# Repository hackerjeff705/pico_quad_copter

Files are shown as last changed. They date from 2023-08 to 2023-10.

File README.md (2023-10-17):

# pico_quad_copter Flight controller code overview
The flight controller code is responsible for reading the data from the various sensors, calculating the PID outputs, and setting the speed of the motors.

## Sensor input

The first section of the code reads the data from the various sensors on the flight controller. This includes the gyro data, the accelerometer data, and the receiver input data.

The gyro data is used to measure the angular rate of the drone. The accelerometer data is used to measure the acceleration of the drone. The receiver input data is used to control the drone.

## PID controller

The next section of the code calculates the PID outputs for the roll, pitch, and yaw axes. The PID controller is a control loop feedback mechanism that is used to maintain a desired setpoint. In this case, the desired setpoint is the angle of the drone.

The PID controller calculates the PID outputs using the following equation:

```PID output = Kp * error + Ki * integral + Kd * derivative```

where:
* ```Kp``` is the proportional gain
* ```Ki``` is the integral gain
* ```Kd``` is the derivative gain
* ```error``` is the difference between the desired setpoint and the current value
* ```integral``` is the sum of the past errors
* ```derivative``` is the rate of change of the error signal

The PID outputs are then limited to a maximum value to prevent overdriving the motors.

The calculate_pid() function that you provided is used to calculate the PID outputs for the roll, pitch, and yaw axes of a drone. The PID outputs are then used to control the speed of the motors.

The function works as follows:
* For each axis (roll, pitch, and yaw):
  * Calculate the PID error by subtracting the desired angular rate (PID setpoint) from the actual angular rate (gyro input).
  * Calculate the integral term by adding the product of the PID error and the integral gain to the integral memory variable.
  * Calculate the derivative term by subtracting the previous PID error from the current PID error and multiplying by the derivative gain.
  * Calculate the PID output by summing the proportional, integral, and derivative terms.
  * Limit the PID output to the maximum value for that axis.

## Motor control

The last section of the code sets the speed of the motors based on the PID outputs. The speed of the motors is controlled by sending a PWM signal to the electronic speed controllers (ESCs).

The ESCs then convert the PWM signal to a DC voltage, which controls the speed of the motors.

## Working systems

The flight controller code can be divided into the following working systems:
* Sensor input system: This system reads the data from the various sensors on the flight controller.
* PID controller system: This system calculates the PID outputs for the roll, pitch, and yaw axes.
* Motor control system: This system sets the speed of the motors based on the PID outputs.

These three systems work together to control the flight of the drone. The sensor input system provides the data needed by the PID controller system to calculate the PID outputs. The PID controller system calculates the PID outputs needed to maintain the desired angle of the drone. The motor control system then sets the speed of the motors based on the PID outputs, which causes the drone to move in the desired direction.

## Additional notes

* The flight controller code is a complex system, but it can be broken down into these three basic working systems. By understanding how these systems work together, you can better understand how the flight controller controls the flight of the drone.
* The PID gains are important parameters that affect the performance of the flight controller. The PID gains need to be tuned to achieve optimal performance.
* The flight controller code is typically written in C or C++.

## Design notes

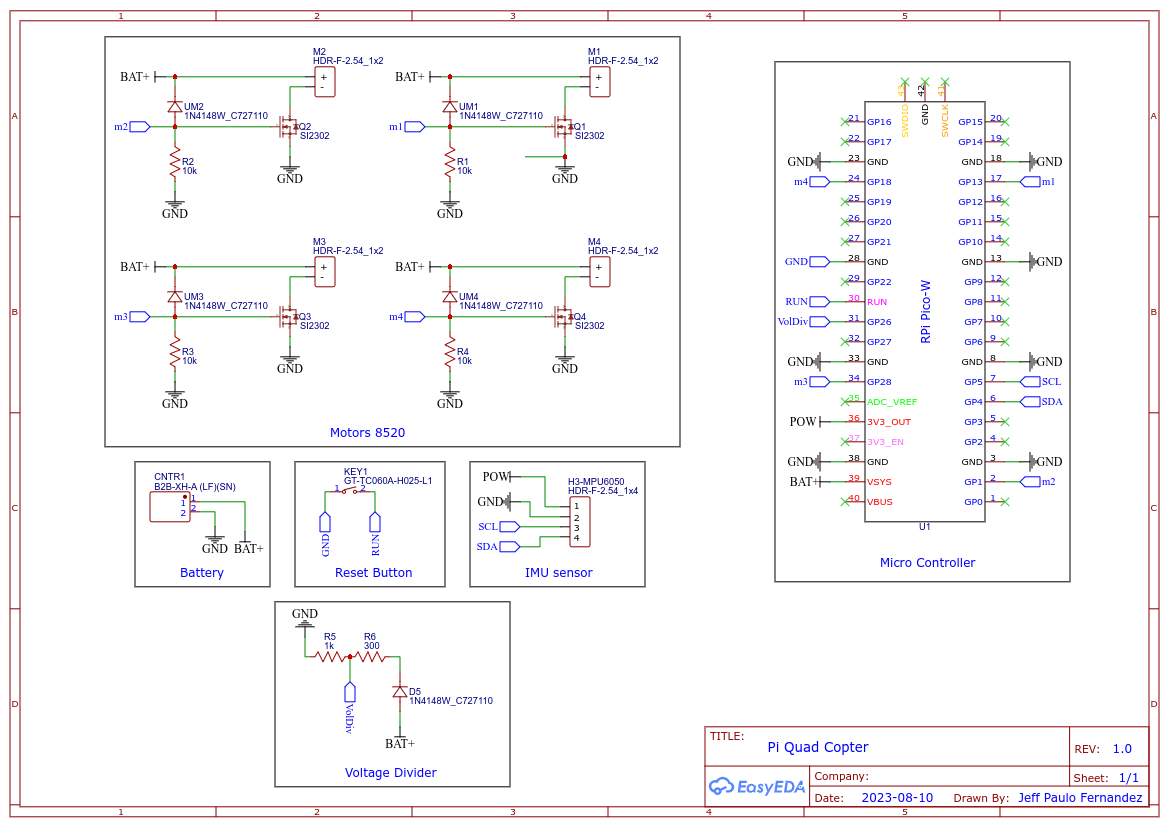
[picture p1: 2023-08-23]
hardware/schematic/Schematic_pi_quad_2023-08-23.png

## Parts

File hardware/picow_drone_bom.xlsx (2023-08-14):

 |  |  | TOTAL ESTIMATE | $59.3396
FINAL ASSEMBLY
Part name | MPN | qty | unit price | total price | link | notes | needed for PCB design?
8520 Drone frame |  | 1 | $12.6900 | $12.6900 | https://www.amazon.com/usmile-Lightweight-Brushed-Quadcopter-Support/dp/B01MU440T0 | Usmile® Super Lightweight 100mm Micro Brushed Carbon Fiber Quadcopter Frame for Mini Micro FPV Racing Support for 820 8.5 * 20mm Motor | N
Raspberry Pi Pico W | 5544 | 1 | $7.0000 | $7.0000 | https://www.adafruit.com/product/5544 | Raspberry Pi Pico WH - Pico Wireless with Headers Soldered | N
MPU6050 |  | 1 | $3.3300 | $3.3300 | https://www.amazon.com/HiLetgo-MPU-6050-Accelerometer-Gyroscope-Converter/dp/B00LP25V1A | HiLetgo 3pcs GY-521 MPU-6050 MPU6050 3 Axis Accelerometer Gyroscope Module 6 DOF 6-axis Accelerometer Gyroscope Sensor Module 16 Bit AD Converter Data Output IIC I2C for Arduino - Comes in packs of 3 | N
1S 360mAh Lipo Battery |  | 1 | $4.3300 | $4.3300 | https://www.amazon.com/GAONENG-300mAh-Battery-Powerwhoop-Connector/dp/B07L9RQNC3 | Gaoneng 6pcs 380mAh HV 1S Lipo Battery FPV Battery 60C/120C 3.8V with PH 2.0 Powerwhoop Connector for UZ65 US65 Tiny Whoop Drone Blade Inductrix - comes in packs of | N
8520 Coreless Motor (OPTION 1) |  | 4 | $2.3700 | $9.4800 | https://www.amazon.com/8-5x20mm-15000KV-Coreless-JST-1-25-Connector/dp/B07CFQMF1M | 8pcs 8520 Motor 8.5x20mm 15000KV Brushed Motors 4CW 4CCW Coreless Motor with JST-1.25 Connector for D JI Ryze Tello 720P Camera WiFi FPV RC Quadcopter M80S E013 Plus Tiny 8X Frame Kit etc - comes in packs of 8 - takes 3.2V | N
8520 Coreless Motor (OPTION 2) |  | 4 | $3.7500 | $15.0000 | https://www.amazon.com/USAQ-Coreless-Brushed-8-5x20mm-Propeller/dp/B06Y11C2HL | Set of 4 USAQ 8520 Coreless Brushed Motor 8.5x20mm 53,000rpm 65mm Propeller Set - (Operating Voltage: 3.7-4.2V, Operating Current: 0.08A-0.1A, Speed: 55,000RPM) | N
55mm Propeller (included with motors but I recommend buying extra) |  | 4 | $1.2000 | $4.8000 | https://www.amazon.com/USAQ-Pairs-KingKong-Propellers-Coreless/dp/B077WS9DY7 | USAQ 10 Pairs Kingkong 65mm Propellers for 716 720 8520 Coreless Motor Micro FPV Drone | N
BMP 280 (Not used yet but will be used in future) |  | 1 |  | $0.0000 |  |  | N
1S Lipo charger (OPTIONAL) |  | 1 |  | $0.0000 |  |  | N
FOR BUILDING PCB BOARD
Part name | MPN | qty | unit price | total price | link | notes | needed for PCB design?
si2302 N channel Mosfet | SI2302 | 4 | $0.0346 | $0.1384 | https://www.lcsc.com/product-detail/MOSFETs_BORN-SI2302_C344009.html |  | Y
1N4148WDiode | 1N4148W | 5 | $0.0066 | $0.0330 | https://www.lcsc.com/product-detail/Switching-Diode_TWGMC-1N4148W_C727110.html | 1N4148 | Y
300 ohm resistor | 0603WAF3000T5E | 1 | $0.0011 | $0.0011 | https://www.lcsc.com/product-detail/Chip-span-style-background-color-ff0-Resistor-span-Surface-Mount_UNI-ROYAL-Uniroyal-Elec-0603WAF3000T5E_C23025.html |  | Y
10k ohm resistor | 0603WAF1002T5E | 4 | $0.0009 | $0.0036 | https://www.lcsc.com/product-detail/Chip-span-style-background-color-ff0-Resistor-span-Surface-Mount_UNI-ROYAL-Uniroyal-Elec-0603WAF1002T5E_C25804.html |  | Y
1k ohm resistor | 0603WAF1001T5E | 1 | $0.0006 | $0.0006 | https://www.lcsc.com/product-detail/Chip-span-style-background-color-ff0-Resistor-span-Surface-Mount_UNI-ROYAL-Uniroyal-Elec-0603WAF1001T5E_C21190.html |  | Y
Male Pin headers | PZ254V-11-03P | 44 | $0.0162 | $0.7128 | https://www.lcsc.com/product-detail/Pin-span-style-background-color-ff0-Headers-span_XFCN-PZ254V-11-03P_C2937625.html | min qty 50 | Y
Female Pin headers | C2718488 | 40 | $0.0430 | $1.7200 | https://www.lcsc.com/product-detail/span-style-background-color-ff0-Female-span-Headers_BOOMELE-Boom-Precision-Elec-C2718488_C2718488.html | min qty 10 | Y
XH male connector | B2B-XH-A(LF)(SN) | 1 | $0.0328 | $0.0328 | https://www.lcsc.com/product-detail/Wire-To-Board-Wire-To-Wire-Connector_span-style-background-color-ff0-JST-span-Sales-America-B2B-XH-A-LF-SN_C158012.html |  | Y
Push Button | GT-TC060A-H025-L1 | 1 | $0.0673 | $0.0673 | https://www.lcsc.com/product-detail/Tactile-Switches_G-span-style-background-color-ff0-Switch-span-GT-TC060A-H025-L1_C5117870.html |  | Y

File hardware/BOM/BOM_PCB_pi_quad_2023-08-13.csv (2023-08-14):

Name | Designator | Footprint | Supplier Part
1N4148W_C727110 | D5,UM1,UM2,UM3,UM4 | SOD-123_L3.1-W1.7-LS3.7-RD | C727110
GT-TC060A-H025-L1 | KEY1 | SW-SMD_L6.1-W3.5-LS8.0 | C5117870
SI2302 | Q1,Q2,Q3,Q4 | SOT-23-3_L2.9-W1.3-P1.90-LS2.4-BR | C181087
10k | R1,R2,R3,R4 | R0603 | C25804
1k | R5 | R0603 | C21190
300 | R6 | R0603 | C23025
B2B-XH-A (LF)(SN) | CNTR1 | CONN-TH_B2B-XH-A-LF-SN | C158012
HDR-F-2.54_1x4 | H3-MPU6050 | HDR-F-2.54_1X4 | C225501
HDR-F-2.54_1x2 | M1,M2,M3,M4 | HDR-F-2.54_1X2 | C49661
C2718488 | U1 | RPI PICO-W | C2718488

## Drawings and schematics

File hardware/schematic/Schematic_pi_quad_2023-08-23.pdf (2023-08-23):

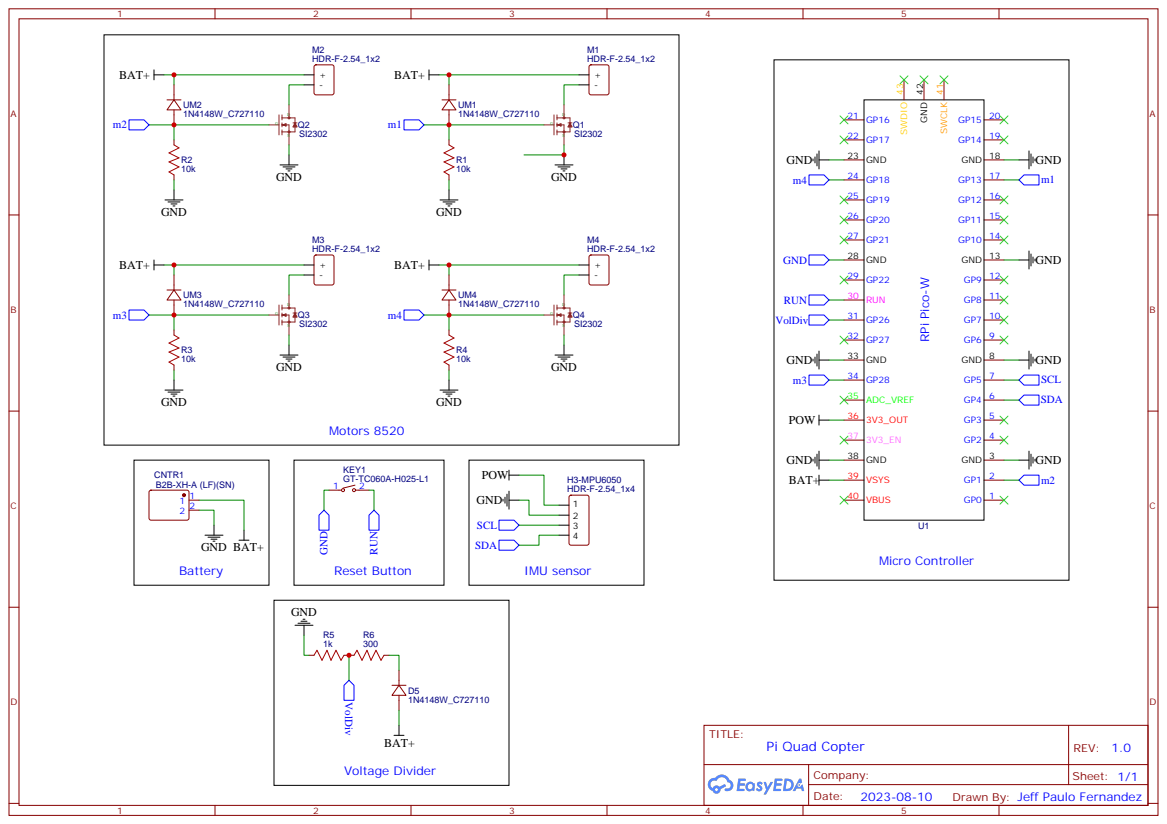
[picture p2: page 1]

Drawn By: Jeff Paulo Fernandez

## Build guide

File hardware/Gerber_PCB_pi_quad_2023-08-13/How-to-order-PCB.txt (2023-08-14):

How to Order PCB

Please refer to:
https://docs.easyeda.com/en/PCB/Order-PCB

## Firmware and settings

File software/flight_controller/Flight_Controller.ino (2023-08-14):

#include <Wire.h>                          //Include the Wire.h library so we can communicate with the gyro.
#include <WiFi.h>
#include <WiFiUdp.h>

#define I2C_CLK_FREQ 400000 // 400kHz
const u_int8_t IMUAddress = 0x68;  // Address for MPU6050 IMU sensor

#ifndef APSSID
#define APSSID "PicoW"
#define APPSW "password"
#endif
#define UDP_PKT_MAX_SIZE 16

unsigned int localPort = 8888;
char packetBuffer[UDP_PKT_MAX_SIZE + 1];

WiFiUDP Udp;  // Object for WiFi UDP class

#define MOT_TOP_LEFT 18
#define MOT_TOP_RIGHT 13
#define MOT_BOTTOM_LEFT 28
#define MOT_BOTTOM_RIGHT 1
#define sensitivity 2

///////////////////////////////////////////////////////////////////////////////////////////////////////////////////////////////////////
//PID gain and limit settings
///////////////////////////////////////////////////////////////////////////////////////////////////////////////////////////////////////
float pid_p_gain_roll = 1.3;               //Gain setting for the roll P-controller was 2.05
float pid_i_gain_roll = 0.013;              //Gain setting for the roll I-controller 0.04
float pid_d_gain_roll = 14.0;              //Gain setting for the roll D-controller was 11.0
int pid_max_roll = 300;                    //Maximum output of the PID-controller (+/-)

float pid_p_gain_pitch = pid_p_gain_roll;  //Gain setting for the pitch P-controller.
float pid_i_gain_pitch = pid_i_gain_roll;  //Gain setting for the pitch I-controller.
float pid_d_gain_pitch = pid_d_gain_roll;  //Gain setting for the pitch D-controller.
int pid_max_pitch = pid_max_roll;          //Maximum output of the PID-controller (+/-)

float pid_p_gain_yaw = 8.5;                //Gain setting for the pitch P-controller. //4.0
float pid_i_gain_yaw = 0.005;               //Gain setting for the pitch I-controller. //0.02
float pid_d_gain_yaw = 0.0;                //Gain setting for the pitch D-controller.
int pid_max_yaw = 300;                     //Maximum output of the PID-controller (+/-)

boolean auto_level = true;                 //Auto level on (true) or off (false)

///////////////////////////////////////////////////////////////////////////////////////////////////////////////////////////////////////
//Declaring global variables
///////////////////////////////////////////////////////////////////////////////////////////////////////////////////////////////////////
byte last_channel_1, last_channel_2, last_channel_3, last_channel_4;
byte highByte, lowByte;
volatile int receiver_input_channel_1 = 0, receiver_input_channel_2 = 0, receiver_input_channel_3 = 0, receiver_input_channel_4 = 0;
int counter_channel_1, counter_channel_2, counter_channel_3, counter_channel_4, loop_counter;
int esc_1, esc_2, esc_3, esc_4;
int throttle, battery_voltage;
int cal_int, start, gyro_address;
int receiver_input[5];
int temperature;
int16_t acc_axis[4], gyro_axis[4];
float roll_level_adjust, pitch_level_adjust;

long acc_x, acc_y, acc_z, acc_total_vector;
unsigned long timer_channel_1, timer_channel_2, timer_channel_3, timer_channel_4, esc_timer, esc_loop_timer;
unsigned long timer_1, timer_2, timer_3, timer_4, current_time;
unsigned long loop_timer;
double gyro_pitch, gyro_roll, gyro_yaw;
double gyro_axis_cal[4];
float pid_error_temp;
float pid_i_mem_roll, pid_roll_setpoint, gyro_roll_input, pid_output_roll, pid_last_roll_d_error;
float pid_i_mem_pitch, pid_pitch_setpoint, gyro_pitch_input, pid_output_pitch, pid_last_pitch_d_error;
float pid_i_mem_yaw, pid_yaw_setpoint, gyro_yaw_input, pid_output_yaw, pid_last_yaw_d_error;
float angle_roll_acc, angle_pitch_acc, angle_pitch, angle_roll;
boolean gyro_angles_set;

///////////////////////////////////////////////////////////////////////////////////////////////////////////////////////////////////////
//Setup routine
///////////////////////////////////////////////////////////////////////////////////////////////////////////////////////////////////////
void setup(){
  
  analogWriteFreq(500); // PWM frequency 500 Hz
  analogWriteRange(1000); // value coresponding to 100% PWM duty cycle

  Serial.begin(115200);
  gyro_address = IMUAddress;      
  Wire.setClock(I2C_CLK_FREQ);   
  Wire.begin();                                                             //Start the I2C as master.

  pinMode(MOT_TOP_LEFT, OUTPUT);
  pinMode(MOT_TOP_RIGHT, OUTPUT);
  pinMode(MOT_BOTTOM_LEFT, OUTPUT);
  pinMode(MOT_BOTTOM_RIGHT, OUTPUT);
  pinMode(LED_BUILTIN, OUTPUT);
  analogWrite(MOT_TOP_LEFT, 0);
  analogWrite(MOT_TOP_RIGHT, 0);
  analogWrite(MOT_BOTTOM_LEFT, 0);
  analogWrite(MOT_BOTTOM_RIGHT, 0);
  
  //Use the led on the Arduino for startup indication.
  digitalWrite(LED_BUILTIN,HIGH);                                                    //Turn on the warning led.

  set_gyro_registers();                                                     //Set the specific gyro registers.

  //Let's take multiple gyro data samples so we can determine the average gyro offset (calibration).
  for (cal_int = 0; cal_int < 2000 ; cal_int ++){                           //Take 2000 readings for calibration.
    if(cal_int % 15 == 0)
      digitalWrite(LED_BUILTIN, !digitalRead(LED_BUILTIN));                //Change the led status to indicate calibration.
    gyro_signalen();                                                        //Read the gyro output.
    gyro_axis_cal[1] += gyro_axis[1];   
    gyro_axis_cal[2] += gyro_axis[2];
    gyro_axis_cal[3] += gyro_axis[3];
    delay(4);                                                               //Wait 3 milliseconds before the next loop.
  }
  //Now that we have 2000 measures, we need to devide by 2000 to get the average gyro offset.
  gyro_axis_cal[1] /= 2000;                                                 //Divide the roll total by 2000.
  gyro_axis_cal[2] /= 2000;                                                 //Divide the pitch total by 2000.
  gyro_axis_cal[3] /= 2000;                                                 //Divide the yaw total by 2000.                                                //Set PCINT3 (digital input 11)to trigger an interrupt on state change.

  WiFi.mode(WIFI_AP);
  WiFi.begin(APSSID, APPSW);
  while(WiFi.status() != WL_CONNECTED) {
    Serial.print('.');    
    delay(500);    
  }
  Udp.begin(localPort);  
  //Wait until the receiver is active and the throtle is set to the lower position.
  while(receiver_input_channel_3 < 990 || receiver_input_channel_3 > 1020 || receiver_input_channel_4 < 1400){
    int packetSize = Udp.parsePacket();
    if(packetSize) {
      int n = Udp.read(packetBuffer, UDP_PKT_MAX_SIZE);
      packetBuffer[n] = '\0';
      char ch1[5], ch2[5], ch3[5], ch4[5];
      ch1[4] = '\0'; ch2[4] = '\0'; ch3[4] = '\0'; ch4[4] = '\0';
      for(int i=0; i<4; i++) {
        ch4[i] = packetBuffer[i];
        ch3[i] = packetBuffer[i+4];
        ch1[i] = packetBuffer[i+8];
        ch2[i] = packetBuffer[i+12];     
      }
      receiver_input_channel_1 = atoi(ch1); // ROLL
      receiver_input_channel_2 = atoi(ch2); // PITCH
      receiver_input_channel_3 = atoi(ch3); // THROTTLE
      receiver_input_channel_4 = atoi(ch4); // YAW
    }
    start ++;
    delay(3);                                                               //Wait 3 milliseconds before the next loop.
    if(start == 125){                                                       //Every 125 loops (500ms).
      digitalWrite(LED_BUILTIN, !digitalRead(LED_BUILTIN));                                   //Change the led status.
      start = 0;                                                            //Start again at 0.
    }
  }
  start = 0;                                                                //Set start back to 0.

  //Load the battery voltage to the battery_voltage variable.
  //65 is the voltage compensation for the diode.
  //12.6V equals ~5V @ Analog 0.
  //12.6V equals 1023 analogRead(0).
  //1260 / 1023 = 1.2317.
  //The variable battery_voltage holds 1050 if the battery voltage is 10.5V.
  //battery_voltage = (analogRead(0) + 65) * 1.2317;

  loop_timer = micros();                                                    //Set the timer for the next loop.

  //When everything is done, turn off the led.
  digitalWrite(LED_BUILTIN,LOW);                                                     //Turn off the warning led.
}
///////////////////////////////////////////////////////////////////////////////////////////////////////////////////////////////////////
//Main program loop
///////////////////////////////////////////////////////////////////////////////////////////////////////////////////////////////////////
void loop(){
  int packetSize = Udp.parsePacket();
  if(packetSize) {
      int n = Udp.read(packetBuffer, UDP_PKT_MAX_SIZE);
      packetBuffer[n] = '\0';
      char ch1[5], ch2[5], ch3[5], ch4[5];
      ch1[4] = '\0'; ch2[4] = '\0'; ch3[4] = '\0'; ch4[4] = '\0';
      for(int i=0; i<4; i++) {
        ch4[i] = packetBuffer[i];
        ch3[i] = packetBuffer[i+4];
        ch1[i] = packetBuffer[i+8];
        ch2[i] = packetBuffer[i+12];     
      }
      receiver_input_channel_1 = atoi(ch1); // ROLL
      receiver_input_channel_2 = atoi(ch2); // PITCH
      receiver_input_channel_3 = atoi(ch3); // THROTTLE
      receiver_input_channel_4 = atoi(ch4); // YAW
    }

  //65.5 = 1 deg/sec (check the datasheet of the MPU-6050 for more information).
  gyro_roll_input = (gyro_roll_input * 0.7) + ((gyro_roll / 65.5) * 0.3);   //Gyro pid input is deg/sec.
  gyro_pitch_input = (gyro_pitch_input * 0.7) + ((gyro_pitch / 65.5) * 0.3);//Gyro pid input is deg/sec.
  gyro_yaw_input = (gyro_yaw_input * 0.7) + ((gyro_yaw / 65.5) * 0.3);      //Gyro pid input is deg/sec.

//  Serial.print(gyro_roll_input);
//  Serial.print(", ");
//  Serial.print(gyro_pitch_input);
//  Serial.print(", ");
//  Serial.print(gyro_yaw_input);
//  Serial.println();
//  

  ////////////////////////////////////////////////////////////////////////////////////////////////////
  //This is the added IMU code from the videos:
  //https://youtu.be/4BoIE8YQwM8
  //https://youtu.be/j-kE0AMEWy4
  ////////////////////////////////////////////////////////////////////////////////////////////////////
  
  //Gyro angle calculations
  //0.0000611 = 1 / (250Hz / 65.5)
  angle_pitch += gyro_pitch * 0.0000611;                                    //Calculate the traveled pitch angle and add this to the angle_pitch variable.
  angle_roll += gyro_roll * 0.0000611;                                      //Calculate the traveled roll angle and add this to the angle_roll variable.

  //0.000001066 = 0.0000611 * (3.142(PI) / 180degr) The Arduino sin function is in radians
  angle_pitch -= angle_roll * sin(gyro_yaw * 0.000001066);                  //If the IMU has yawed transfer the roll angle to the pitch angel.
  angle_roll += angle_pitch * sin(gyro_yaw * 0.000001066);                  //If the IMU has yawed transfer the pitch angle to the roll angel.

  //Accelerometer angle calculations
  acc_total_vector = sqrt((acc_x*acc_x)+(acc_y*acc_y)+(acc_z*acc_z));       //Calculate the total accelerometer vector.
  
  if(abs(acc_y) < acc_total_vector){                                        //Prevent the asin function to produce a NaN
    angle_pitch_acc = asin((float)acc_y/acc_total_vector)* 57.296;          //Calculate the pitch angle.
  }
  if(abs(acc_x) < acc_total_vector){                                        //Prevent the asin function to produce a NaN
    angle_roll_acc = asin((float)acc_x/acc_total_vector)* -57.296;          //Calculate the roll angle.
  }
  
  //Place the MPU-6050 spirit level and note the values in the following two lines for calibration.
  angle_pitch_acc -= 0.0;                                                   //Accelerometer calibration value for pitch.
  angle_roll_acc -= 0.0;                                                    //Accelerometer calibration value for roll.
  
  angle_pitch = angle_pitch * 0.9996 + angle_pitch_acc * 0.0004;            //Correct the drift of the gyro pitch angle with the accelerometer pitch angle.
  angle_roll = angle_roll * 0.9996 + angle_roll_acc * 0.0004;               //Correct the drift of the gyro roll angle with the accelerometer roll angle.

  pitch_level_adjust = angle_pitch * 15;                                    //Calculate the pitch angle correction
  roll_level_adjust = angle_roll * 15;                                      //Calculate the roll angle correction

  if(!auto_level){                                                          //If the quadcopter is not in auto-level mode
    pitch_level_adjust = 0;                                                 //Set the pitch angle correction to zero.
    roll_level_adjust = 0;                                                  //Set the roll angle correcion to zero.
  }


  //For starting the motors: throttle low and yaw left (step 1).
  if(receiver_input_channel_3 < 1050 && receiver_input_channel_4 < 1050)start = 1;
  //When yaw stick is back in the center position start the motors (step 2).
  if(start == 1 && receiver_input_channel_3 < 1050 && receiver_input_channel_4 > 1450){
    start = 2;

    angle_pitch = angle_pitch_acc;                                          //Set the gyro pitch angle equal to the accelerometer pitch angle when the quadcopter is started.
    angle_roll = angle_roll_acc;                                            //Set the gyro roll angle equal to the accelerometer roll angle when the quadcopter is started.
    gyro_angles_set = true;                                                 //Set the IMU started flag.

    //Reset the PID controllers for a bumpless start.
    pid_i_mem_roll = 0;
    pid_last_roll_d_error = 0;
    pid_i_mem_pitch = 0;
    pid_last_pitch_d_error = 0;
    pid_i_mem_yaw = 0;
    pid_last_yaw_d_error = 0;
  }
  //Stopping the motors: throttle low and yaw right.
  if(start == 2 && receiver_input_channel_3 < 1050 && receiver_input_channel_4 > 1950)start = 0;

  //The PID set point in degrees per second is determined by the roll receiver input.
  //In the case of deviding by 3 the max roll rate is aprox 164 degrees per second ( (500-8)/3 = 164d/s ).
  pid_roll_setpoint = 0;
  //We need a little dead band of 16us for better results.
  if(receiver_input_channel_1 > 1508)pid_roll_setpoint = receiver_input_channel_1 - 1508;
  else if(receiver_input_channel_1 < 1492)pid_roll_setpoint = receiver_input_channel_1 - 1492;

  pid_roll_setpoint -= roll_level_adjust;                                   //Subtract the angle correction from the standardized receiver roll input value.
  pid_roll_setpoint /= 3.0;                                                 //Divide the setpoint for the PID roll controller by 3 to get angles in degrees.


  //The PID set point in degrees per second is determined by the pitch receiver input.
  //In the case of deviding by 3 the max pitch rate is aprox 164 degrees per second ( (500-8)/3 = 164d/s ).
  pid_pitch_setpoint = 0;
  //We need a little dead band of 16us for better results.
  if(receiver_input_channel_2 > 1508)pid_pitch_setpoint = receiver_input_channel_2 - 1508;
  else if(receiver_input_channel_2 < 1492)pid_pitch_setpoint = receiver_input_channel_2 - 1492;

  pid_pitch_setpoint -= pitch_level_adjust;                                  //Subtract the angle correction from the standardized receiver pitch input value.
  pid_pitch_setpoint /= 3.0;                                                 //Divide the setpoint for the PID pitch controller by 3 to get angles in degrees.

  //The PID set point in degrees per second is determined by the yaw receiver input.
  //In the case of deviding by 3 the max yaw rate is aprox 164 degrees per second ( (500-8)/3 = 164d/s ).
  pid_yaw_setpoint = 0;
  //We need a little dead band of 16us for better results.
  if(receiver_input_channel_3 > 1050){ //Do not yaw when turning off the motors.
    if(receiver_input_channel_4 > 1508)pid_yaw_setpoint = (receiver_input_channel_4 - 1508)/3.0;
    else if(receiver_input_channel_4 < 1492)pid_yaw_setpoint = (receiver_input_channel_4 - 1492)/3.0;
  }
  
  calculate_pid();                                                            //PID inputs are known. So we can calculate the pid output.

  //The battery voltage is needed for compensation.
  //A complementary filter is used to reduce noise.
  //0.09853 = 0.08 * 1.2317.
  //battery_voltage = battery_voltage * 0.92 + (analogRead(0) + 65) * 0.09853;

  //Turn on the led if battery voltage is to low.
  //if(battery_voltage < 1000 && battery_voltage > 600)digitalWrite(12, HIGH);


  throttle = receiver_input_channel_3;                                      //We need the throttle signal as a base signal.

  if (start == 2){                                                          //The motors are started.
    if (throttle > 1800) throttle = 1800;                                   //We need some room to keep full control at full throttle.
    esc_1 = throttle - pid_output_pitch + pid_output_roll - pid_output_yaw; //Calculate the pulse for esc 1 (front-right - CCW)
    esc_2 = throttle + pid_output_pitch + pid_output_roll + pid_output_yaw; //Calculate the pulse for esc 2 (rear-right - CW)
    esc_3 = throttle + pid_output_pitch - pid_output_roll - pid_output_yaw; //Calculate the pulse for esc 3 (rear-left - CCW)
    esc_4 = throttle - pid_output_pitch - pid_output_roll + pid_output_yaw; //Calculate the pulse for esc 4 (front-left - CW)

    // if (battery_voltage < 1240 && battery_voltage > 800){                   //Is the battery connected?
    //   esc_1 += esc_1 * ((1240 - battery_voltage)/(float)3500);              //Compensate the esc-1 pulse for voltage drop.
    //   esc_2 += esc_2 * ((1240 - battery_voltage)/(float)3500);              //Compensate the esc-2 pulse for voltage drop.
    //   esc_3 += esc_3 * ((1240 - battery_voltage)/(float)3500);              //Compensate the esc-3 pulse for voltage drop.
    //   esc_4 += esc_4 * ((1240 - battery_voltage)/(float)3500);              //Compensate the esc-4 pulse for voltage drop.
    // } 

    if (esc_1 < 1100) esc_1 = 1100;                                         //Keep the motors running.
    if (esc_2 < 1100) esc_2 = 1100;                                         //Keep the motors running.
    if (esc_3 < 1100) esc_3 = 1100;                                         //Keep the motors running.
    if (esc_4 < 1100) esc_4 = 1100;                                         //Keep the motors running.

    if(esc_1 > 2000)esc_1 = 2000;                                           //Limit the esc-1 pulse to 2000us.
    if(esc_2 > 2000)esc_2 = 2000;                                           //Limit the esc-2 pulse to 2000us.
    if(esc_3 > 2000)esc_3 = 2000;                                           //Limit the esc-3 pulse to 2000us.
    if(esc_4 > 2000)esc_4 = 2000;                                           //Limit the esc-4 pulse to 2000us.  
  }

  else{
    esc_1 = 1000;                                                           //If start is not 2 keep a 1000us pulse for ess-1.
    esc_2 = 1000;                                                           //If start is not 2 keep a 1000us pulse for ess-2.
    esc_3 = 1000;                                                           //If start is not 2 keep a 1000us pulse for ess-3.
    esc_4 = 1000;                                                           //If start is not 2 keep a 1000us pulse for ess-4.
  }

  ////////////////////////////////////////////////////////////////////////////////////////////////////
  //Creating the pulses for the ESC's is explained in this video:
  //https://youtu.be/fqEkVcqxtU8
  ////////////////////////////////////////////////////////////////////////////////////////////////////

  //! ! ! ! ! ! ! ! ! ! ! ! ! ! ! ! ! ! ! ! ! ! ! ! ! ! ! ! ! ! ! ! ! ! ! ! ! ! ! ! ! ! ! ! ! ! ! ! ! !
  //Because of the angle calculation the loop time is getting very important. If the loop time is 
  //longer or shorter than 4000us the angle calculation is off. If you modify the code make sure 
  //that the loop time is still 4000us and no longer! More information can be found on 
  //the Q&A page: 
  //! ! ! ! ! ! ! ! ! ! ! ! ! ! ! ! ! ! ! ! ! ! ! ! ! ! ! ! ! ! ! ! ! ! ! ! ! ! ! ! ! ! ! ! ! ! ! ! ! !
    
  if(micros() - loop_timer > 4050)digitalWrite(LED_BUILTIN, HIGH);                   //Turn on the LED if the loop time exceeds 4050us.
  
  //All the information for controlling the motor's is available.
  //The refresh rate is 250Hz. That means the esc's need there pulse every 4ms.
  while(micros() - loop_timer < 4000);                                      //We wait until 4000us are passed.
  loop_timer = micros();                                                    //Set the timer for the next loop.

  esc_1 = map(esc_1, 1000, 2000, 0, 1000);
  esc_2 = map(esc_2, 1000, 2000, 0, 1000);
  esc_3 = map(esc_3, 1000, 2000, 0, 1000);
  esc_4 = map(esc_4, 1000, 2000, 0, 1000);

  analogWrite(MOT_TOP_RIGHT, esc_1);
  analogWrite(MOT_BOTTOM_RIGHT, esc_2);
  analogWrite(MOT_BOTTOM_LEFT, esc_3);
  analogWrite(MOT_TOP_LEFT, esc_4);
  //There is always 1000us of spare time. So let's do something usefull that is very time consuming.
  //Get the current gyro and receiver data and scale it to degrees per second for the pid calculations.
  gyro_signalen();
}
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

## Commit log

2023-08-14 added hardware files
    [BOM_PCB_pi_quad_2023-08-13.csv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]
2023-08-23 Schematics relabelled
